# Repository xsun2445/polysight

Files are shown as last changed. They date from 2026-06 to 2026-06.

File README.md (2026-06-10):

<h1 align="center">POLySight</h1>

<h3 align="center">Towards Practical Bi-Static Polarimetric Imaging Using Commodity mmWave Radars for Material Sensing</h3>

<p align="center"><i>ACM/IEEE SenSys 2026</i></p>

<p align="center">
  <a href="https://xsun2445.github.io/polysight/">Project Page</a> |
  <a href="https://huggingface.co/datasets/xinghs/polysight">Dataset (Hugging Face)</a>
</p>

<p align="center">
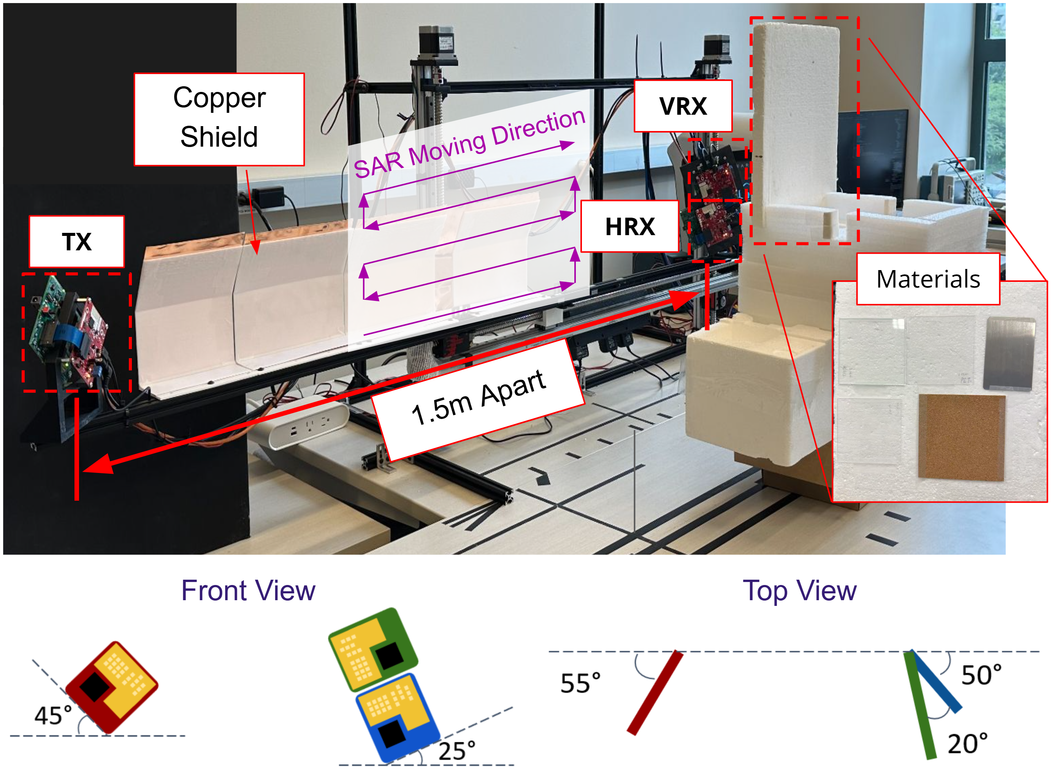
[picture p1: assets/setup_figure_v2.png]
Measurement setup
  
</p>

Polarimetric bistatic SAR imaging system for contactless material characterization at 77 GHz.

A single TX board (TI AWR2243) illuminates the scene while two spatially separated RX boards capture orthogonal polarizations (H, V). A 2-D motorized raster stage synthesizes a large aperture. The polarimetric ratio H/V, combined with Fresnel reflection inversion, yields complex permittivity (ε′ − jε″) of materials without physical contact.

<p align="center">
  Qualitative results
</p>

## Setup

```bash
uv venv
uv pip install -r requirements.txt
```

GPU acceleration (SAR generation) requires CUDA 12.x and CuPy.

## Pipeline

```
Collection → Decode/Sync → SAR Generation → Labeling → Permittivity Extraction
(collect.py)   (decode.py)   (sar.py + GPU)   (notebook)   (Fresnel inversion)
```

Detailed tutorials/implementations are inside the notebooks folder:
1. [Synchronization](notebooks/01_synchronization.ipynb)
2. [SAR generation](notebooks/02_sar_generation.ipynb)
3. [Liquid materials](notebooks/03_eval_liquids.ipynb)
4. [Solid and powder materials](notebooks/04_eval_solids.ipynb)
5. [Case study on sugar water concentration](notebooks/05_concentration.ipynb)

## Method

1. **Bistatic geometry**: TX and RX separated ~1.5 m, incidence angle 55°–60°
2. **Polarimetric ratio**: `div = SAR_H / SAR_V` (complex-valued)
3. **Amplitude → Fresnel ratio**: Normalize against metal reference, correct for antenna axial ratio, compute `p = tan(θ_pol)`
4. **Phase → loss tangent**: Extract referenced phase from H/V ratio
5. **Complex Fresnel ratio**: `p_complex = |p| · exp(−jφ)`
6. **Inversion**: `ε = (1 + 4p/(1−p)² · sin²θ_i) · tan²θ_i`
7. **Result**: `ε′ = Re(ε)`, `ε″ = |Im(ε)|`

## Dataset

The dataset contains 70 synchronized radar collections across 36 materials including plastics, ceramics, glass, wood, rubber, metals, liquids, and powders, measured at 55° and 60° incidence angles.

| Folder | Size | Contents |
|---|---|---|
| `raw/` | ~72 GB  | 70 synchronized radar cubes (~1 GB each)  |
| `labels/` | ~66 MB  | 84 SAR image collections with labels |
| `materials/` | ~1 MB | 72 cropped material sample files (.pkl) |
| `unsynced/`  | ~35 GB  | 2 example raw unsynchronized ADC captures |

See [data/README.md](data/README.md) for more details and selective downloading.

## Hardware

See [hardware/README.md](hardware/README.md) for more details

- **Radar**: 3 sets of TI AWR2243 FMCW (76–81 GHz) + DCA1000 EVM (ADC capture). Currently requires 3 PCs to config and re-trigger each of the radar with TI mmWaveStudio. todo: command line tool to replace the mmWaveStudio. A similar setup can be found in our MulDar repo: https://github.com/xsun2445/MulDar
- **Synchronization**: Raspberry Pi 4B
- **Motion stage**: 2-axis linear stage, 3 stepper motors + drivers, Arduino-controlled stepper motors

For more details please check out our paper: https://xsun2445.github.io/assets/pdf/Sensys_2026_PolySight.pdf

## Citation

```bibtex
@inproceedings{sun2026towards,
  title={Towards Practical Bi-Static Polarimetric Imaging Using Commodity mmWave Radars for Material Sensing},
  author={Sun, Xinghua and Gadre, Akshay},
  booktitle={Proceedings of the 2026 ACM/IEEE International Conference on Embedded Artificial Intelligence and Sensing Systems},
  pages={172--185},
  year={2026}
}
```

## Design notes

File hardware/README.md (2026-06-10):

# Hardware

<p align="center">
  Measurement setup
</p>

## Setup Overview

The PolySight hardware consists of three subsystems:

- **Radar**: 3 TI AWR2243 FMCW radar boards (76–81 GHz), each paired with a DCA1000 EVM for raw ADC capture. One board transmits (TX), two boards receive orthogonal polarizations (HRX, VRX). The TX and RX are separated by ~1.5 m in a bistatic configuration, with a copper shield isolating the TX antenna. Currently each radar requires a separate PC running TI mmWaveStudio for configuration and triggering.
- **Motion stage**: A 2-axis linear stage rasters the target across the radar aperture to synthesize a large SAR image. The vertical axis uses two stepper motors (left and right) for stability, and the horizontal axis uses one stepper motor. An Arduino controls all three motors via stepper drivers and sends a trigger pulse at each raster position.
- **Synchronization**: A Raspberry Pi 4B receives the trigger pulse from the Arduino (which corresponds to the SAR antenna locations on motion stage) and simultaneously triggers all three radar boards via hardware GPIO pins, ensuring time-aligned ADC captures across boards. Uses [WiringPi-Python-MultiPin](https://github.com/xsun2445/WiringPi-Python-MultiPin) for simultaneous multi-pin GPIO toggling.

## Directory Structure

```
hardware/
├── arduino/
│   └── motor_serialport_control.ino   # Arduino motor + trigger control
├── 3d_models/
│   ├── radar_frame_horizontal.stl     # Radar mounting frame (horizontal)
│   ├── radar_frame_22.5.stl           # Radar mounting frame (22.5° tilt)
│   ├── corner_reflector_30_1.5.stl    # Corner reflector (30 mm, 1.5 mm)
│   └── corner_reflector_50,1.5.stl    # Corner reflector (50 mm, 1.5 mm)
└── README.md
```

## Arduino Motor Control

The Arduino firmware (`motor_serialport_control.ino`) orchestrates the 2-D raster scan:

- **Vertical axis**: 2 stepper motors driven by the same step/direction signals for synchronized movement
- **Horizontal axis**: 1 stepper motor for lateral scanning
- **Trigger output**: GPIO pin 2 sends a pulse at each raster position to the Raspberry Pi
- **Serial interface**: Accepts commands from the host PC to configure scan parameters (speed, step count, grid size)

Pin assignments:

| Pin | Function |
|-----|---|
| 2 | Trigger (to Raspberry Pi) |
| 3, 8 | Vertical left motor (PUL, DIR) |
| 4, 9 | Vertical right motor (PUL, DIR) |
| 5, 10 | Horizontal motor (PUL, DIR) |

## Raspberry Pi Synchronization

The Raspberry Pi 4B acts as the hardware synchronization bridge between the motion stage and the radar boards:

1. Listens for the trigger pulse from the Arduino (one pulse per raster position)
2. Simultaneously toggles multiple GPIO pins to trigger all three AWR2243BOOST boards to start ADC capture
3. Uses [WiringPi-Python-MultiPin](https://github.com/xsun2445/WiringPi-Python-MultiPin) to set multiple GPIO pins in a single register write, minimizing timing offsets between radar boards

## 3D Models

STL files for 3D-printed mounting hardware:

- **Radar frames**: Custom brackets for mounting AWR2243+DCA1000 boards at horizontal or 22.5° tilt angles
- **Corner reflectors**: Calibration targets for SAR image verification

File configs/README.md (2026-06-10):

# Configs

JSON configuration files for Polysight data collection and processing. Each file
defines one aspect of the acquisition setup and is loaded at runtime.

| File | Purpose |
| --- | --- |
| `data_collection_cfg.json` | Scan geometry and per-acquisition radar parameters. |
| `devices_comm_cfg.json` | Chirp profile and communication/triggering setup for all devices. |
| `radar_id.json` | Static identity map of each physical radar board. |

## `data_collection_cfg.json`

Defines the raster scan grid and frame timing for a capture session.

- **Scan grid** — `dx`/`dy` step size, `total_x`/`total_y` extent, `moving_direction`
  (`"row"`/`"column"`), and `initial_position_pointer`.
- **Frame timing** — `num_trigger`, `period_frame`, `num_frame`, `num_chirp`,
  `num_config`, `vibration_pd`, `radar_timeout`.
- **Data shape** — `num_adc` (samples per chirp), `num_ch` (RX channels).
- **Geometry / mounting** — board distances and angles (`board_dist`,
  `txboard_angle_y`, `rxboard_*_angle_*`, `rxboard_tilt_offset`, `object_distance`).
- **Run metadata** — `retrigger_list`, `saving_root_dir`, `description`,
  `packet_zero_filling`.

## `devices_comm_cfg.json`

Defines the radar waveform and how the host talks to each device.

- **`chirp_configs`** — FMCW waveform: `f0`, `slope`, `ramp_time`, `adc_start_time`,
  `num_adc`, `Fs`, plus `activated_tx` / `activated_rx`.
- **`comm_cfg`** — device count and a block per node (`master`, `slave_*`, `motor`,
  `trigger`) giving `radar_name`, `port_type`, IP/serial port, and access port.

## `radar_id.json`

Per-board static identity, keyed by board index: `name` (e.g. `RH`, `RV`, `LS`),
`ip`, `mac`, and `cfg_port` / `data_port`. The `radar_name` referenced in
`devices_comm_cfg.json` maps back to the `name` here.

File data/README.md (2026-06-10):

# PolySight Dataset

Polarimetric bistatic SAR dataset collected with a 77 GHz FMCW radar (TI AWR2243).
Two radar boards receive orthogonal polarizations (RH, RV) while a single TX board
illuminates the scene. A 2-D motorized stage rasters the target across the aperture.

## Directory Structure

```
data/
├── unsynced/          # Raw unsynchronized ADC captures (2 example collections)
│   └── <collection>/
│       ├── RH/                   # Raw DCA1000 captures, H-pol RX (.bin + _log.csv)
│       ├── RV/                   # Raw DCA1000 captures, V-pol RX (.bin + _log.csv)
│       ├── LS/                   # Raw DCA1000 captures, TX (.bin + _log.csv)
│       ├── _adcData/RH/          # Decoded per-frame .npy files, H-pol
│       ├── _adcData/RV/          # Decoded per-frame .npy files, V-pol
│       ├── adcData/RH/           # Synchronized per-frame .npy files, H-pol
│       ├── adcData/RV/           # Synchronized per-frame .npy files, V-pol
│       ├── collection.log
│       ├── data_collection_cfg.json
│       ├── devices_comm_cfg.json
│       └── radar_id.json
│
├── raw/               # Synchronized radar cubes (70 collections, ~72 GB, ~1 GB each)
│   └── <collection>/
│       ├── RH_synced.npy         # Synchronized ADC cube, H-pol receiver
│       ├── RV_synced.npy         # Synchronized ADC cube, V-pol receiver
│       ├── data_collection_cfg.json
│       ├── devices_comm_cfg.json
│       └── radar_id.json
│
├── labels/            # SAR images + bounding-box labels (85 collections)
│   └── <collection>/
│       ├── sar_h.npy             # Complex SAR image, H-pol (150x150, complex64)
│       ├── sar_v.npy             # Complex SAR image, V-pol (150x150, complex64)
│       └── <collection>.json     # Label file (bounding boxes + SAR config)
│
├── materials/                    # Cropped material samples (see below)
│   ├── ceramic_60.pkl
│   ├── water_55.pkl
│   └── ...
│
└── README.md
```

## Download

The polysight dataset is hosted on Hugging face: https://huggingface.co/datasets/xinghs/polysight

Files are downloaded into the current directory, preserving the original folder structure.

| Folder | Size | Contents |
|---|---|---|
| `raw/` | ~72 GB  | 70 synchronized radar cubes (~1 GB each)  |
| `labels/` | ~66 MB  | 84 SAR image collections with labels |
| `materials/` | ~1 MB | 72 cropped material sample files (.pkl) |
| `unsynced/`  | ~35 GB  | 2 example raw unsynchronized ADC captures |

Use `download.py` to selectively download subfolders, install the Hugging Face Hub client:

```bash
pip install huggingface_hub
```

```bash
# List all available folders
python download.py --list

# Download a top-level folder
python download.py materials

# Download specific collections
python download.py labels/20250603_185728_oil_water labels/20250605_194155_water

# Download with glob patterns
python download.py "labels/20250625*"

# Download multiple folders at once
python download.py materials labels raw

# Download everything
python download.py --all
```

---

## Pipeline

```
unsynced/  ──[decode + sync]──>  raw/  ──[SAR generation]──>  labels/  ──[crop]──>  materials/
```

### 1. `unsynced/` - Raw ADC Captures

Raw ADC frames captured by three DCA1000 FPGA boards over Ethernet. Each radar
board produces independent packet streams that are **not yet time-aligned**.
These are provided as examples for reproducing the full decode and synchronization
pipeline (`polysight.collection.decode`). Most users can skip this stage and start
from `raw/`.

### 2. `raw/` - Synchronized Radar Cubes

Time-synchronized 3-D ADC data cubes, one per polarization channel:

- **`RH_synced.npy`** - Horizontal polarization receiver
- **`RV_synced.npy`** - Vertical polarization receiver

Each file is a NumPy array of shape `(num_positions, num_antennas, num_adc_samples)`
containing the decoded, packet-loss-corrected, and cross-board synchronized IF signal.
Generated from `unsynced/` data using `scripts/decode.py`.

### 3. `labels/` - SAR Images + Labels

SAR images generated from `raw/` cubes via GPU-accelerated FFT back-projection
(`scripts/generate_sar.py`, `notebooks/02_sar_generation.ipynb`).

Each collection folder contains:

- **`sar_h.npy`** / **`sar_v.npy`** - Complex-valued SAR images (150x150, complex64)
- **`<collection>.json`** - Metadata and bounding-box labels, created with
  `notebooks/03_labeling.ipynb`

The JSON label file contains:

```json
{
  "description": "1tx, oil, water, copper",
  "labels": {
    "oil":    [x0, y0, x1, y1],
    "water":  [x0, y0, x1, y1],
    "copper": [x0, y0, x1, y1]
  },
  "sar_config": {
    "numX": 350, "numY": 200,
    "dx": 0.002, "dy": 0.002,
    "output_size_x": 150, "output_size_y": 150,
    "chirp_configs": { "f0": 76.01e9, "slope": 38.8e12, ... },
    "antenna_configs": { ... },
    "ant_locs": [[x,y,z], ...],
    "RH_config": { "alignment_configs": { ... }, ... },
    "RV_config": { ... }
  }
}
```

### 4. `materials/` - Cropped Material Samples

Pickled dictionaries containing cropped SAR pixel regions for individual materials,
extracted from labeled SAR images. Each `.pkl` file represents one material measured
at a specific incident angle. Used by the evaluation notebooks for permittivity
estimation and material classification.

**File naming**: `<material>_<angle>.pkl` (e.g., `ceramic_60.pkl`, `water_55.pkl`)

**Structure of each `.pkl` file**:

```python
{
    "name":           str,        # Material name (e.g., "ceramic")
    "thickness":      float,      # Sample thickness in meters (e.g., 0.00127)
    "collection_name": str,       # Source collection (e.g., "20250623_182841_multi")
    "incident_angle": float,      # Measurement angle in degrees (e.g., 60.0)
    "ref_name":       str,        # Reference material name (e.g., "copper")
    "ref_thickness":  float,      # Reference thickness in meters
    "values":         list[ndarray],  # 3 complex64 arrays: [H/V ratio, H, V]
                                      # each shaped (rows, cols) from bounding box
    "ref_values":     list[ndarray],  # Same structure for the reference material
}
```

The `values` and `ref_values` lists each contain 3 arrays corresponding to the
H/V polarimetric ratio, H-pol, and V-pol SAR pixel regions cropped from the
bounding box. The polarimetric ratio (element 0) is used with Fresnel equations
to estimate relative permittivity via `polysight.eval.permittivity.ratio_to_epsilon`.

## Collection Categories

| Category | Count | Description |
|---|---:|---|
| liquids | 11 | Oil, water, soy sauce, syrup, sugar-water series  |
| solids | 24 | Plastics, wood, rubber, metals, composites |
| roughness | 3 | Wood grain orientations, sandpaper grits |
| ablation | 9 | Parameter sensitivity |
| concentration | 7 | Sugar-water concentration gradient (0-6 spoons) |
| ceramics | 8 | Alumina ceramic vs plastic at varying positions |
| misc | 8 | Oil, powder, rubber, PVC, mixed materials |

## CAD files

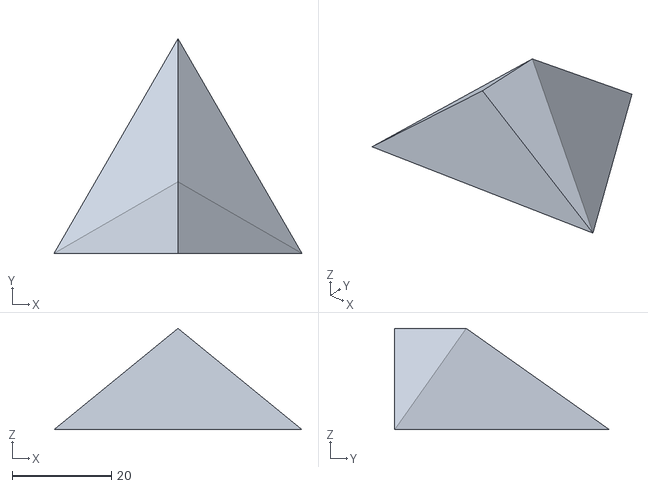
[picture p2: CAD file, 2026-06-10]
hardware/3d_models/corner_reflector_50,1.5.stl
50.0 x 43.3 x 20.4

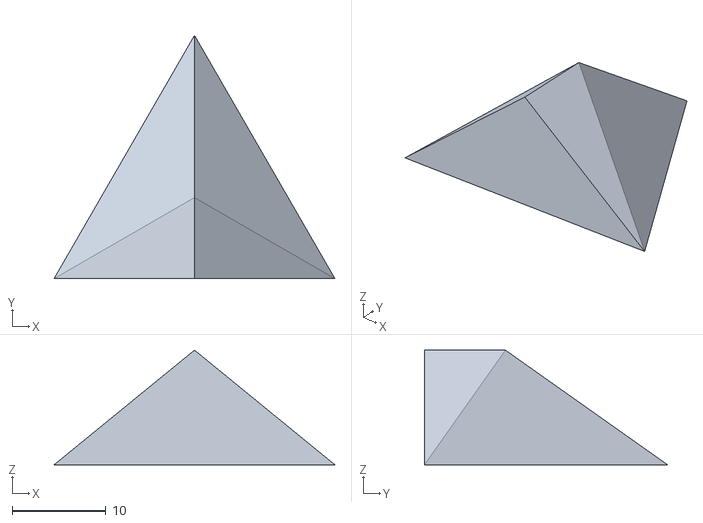
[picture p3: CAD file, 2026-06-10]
hardware/3d_models/corner_reflector_30_1.5.stl
30.0 x 26.0 x 12.2

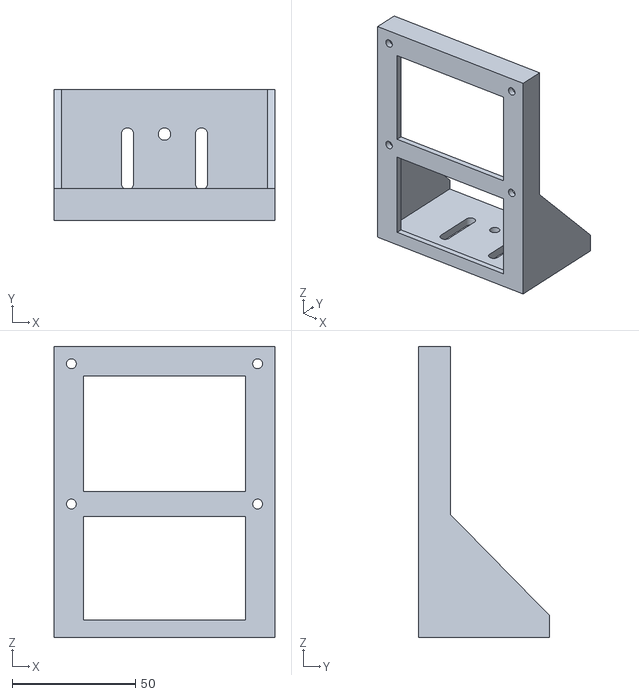
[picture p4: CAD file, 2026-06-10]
hardware/3d_models/radar_frame_horizontal.stl
89.6 x 53.0 x 118.0

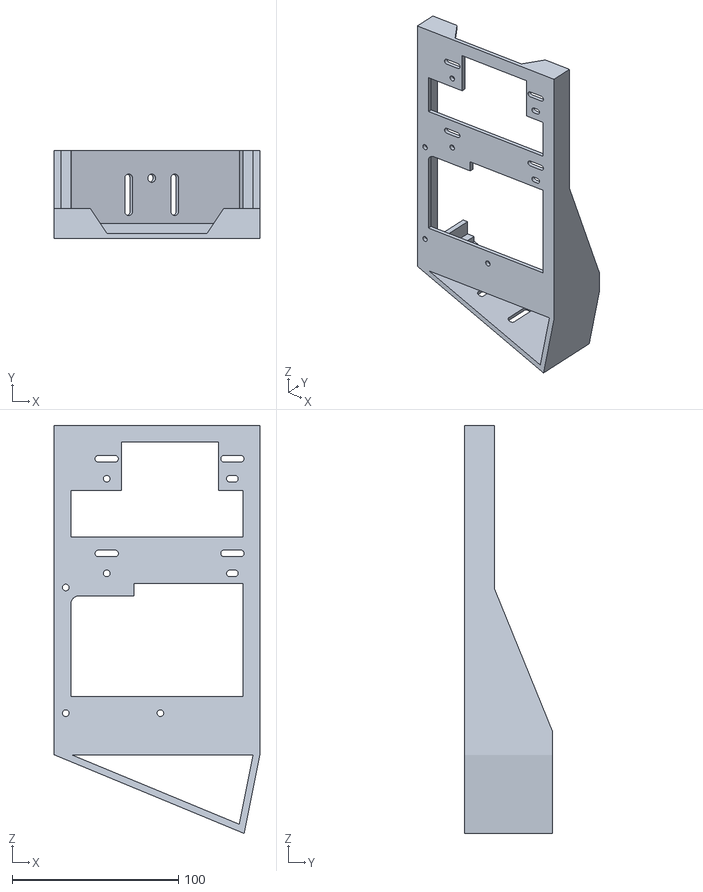
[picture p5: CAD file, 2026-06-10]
hardware/3d_models/radar_frame_22.5.stl
123.7 x 53.0 x 245.3

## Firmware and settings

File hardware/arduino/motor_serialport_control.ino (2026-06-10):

/*
  Combine H (2D) linear guide and another 1D linear guide for synchronous passthrough data collection. 

  Vertical rail: 2 stepper motors (left and right) for better stability, driven by same step signal and direction signal.
  Horizontal rail: 1 stepper motor.
  Trigger: 1 GPIO pin for triggering raspi which will trigger multiple radars through hardware trigger.
*/

#include <AccelStepper.h>
#include <math.h>

// for H rail
#define PUL_Ver_L 3
#define DIR_Ver_L 8
#define PUL_Ver_R 4
#define DIR_Ver_R 9
#define PUL_Hor 5
#define DIR_Hor 10
#define TRIGGER 2

// for 1D rail
#define PUL_1D 6
#define DIR_1D 11

// used as 5V pulled up
#define PULL_UP_0 12
#define PULL_UP_1 13


byte pul_ver_l = B00000001 << PUL_Ver_L;
byte pul_ver_r = B00000001 << PUL_Ver_R;
byte pul_hor = B00000001 << PUL_Hor;
byte trigger = B00000001 << TRIGGER;

byte pul_1d = B00000001 << PUL_1D;


long RATIO = 200;
// float speed = 23; // 50 -> about 40mm/s, // 23 -> 20mm/s
float speed = 6;
unsigned int pd = 1e6/speed/RATIO/2;


void setup() {
  Serial.begin(9600);
  Serial.setTimeout(10);

  DDRD = pul_ver_l|pul_ver_r|pul_hor|trigger|pul_1d;
  PORTD = B00000000;

  // pinMode(PUL_Ver_L, OUTPUT);
  pinMode(DIR_Ver_L, OUTPUT);
  // pinMode(PUL_Ver_R, OUTPUT);
  pinMode(DIR_Ver_R, OUTPUT);
  // pinMode(PUL_Hor, OUTPUT);
  pinMode(DIR_Hor, OUTPUT);
  // pinMode(TRIGGER, OUTPUT);
  pinMode(DIR_1D, OUTPUT);

  // pull up
  pinMode(PULL_UP_0, OUTPUT);
  pinMode(PULL_UP_1, OUTPUT);
  digitalWrite(PULL_UP_0, HIGH);
  digitalWrite(PULL_UP_1, HIGH);

}


void loop() {

  // Serial.println("Enter x,y:");
  while (Serial.available() == 0) {}     //wait for data available
  String teststr = Serial.readString();  //read until timeout
  teststr.trim();                        // remove any \r \n whitespace at the end of the String

  // input string will has length 4 each representing: H_x, H_y, 1D_x, step_to_trigger

  char *token = strtok(teststr.c_str(), ",");
  double cmdAry[4];
  int i=0;
  while( token != NULL ) {
      // cmdAry[i++] = atoi(token);
      cmdAry[i++] = atof(token);
      // cmdAry[i++] = strtol(token);
      token = strtok(NULL, ",");
  }
  
  double posx = cmdAry[0];
  double posy = cmdAry[1];
  double pos1d = cmdAry[2];
  double num_to_trigger;

  if (i > 3){
    num_to_trigger = cmdAry[3];
    pulse_train_trigger_byte(posx, posy, pos1d, int(round(num_to_trigger)));
  }else{
    pulse_train_byte(posx, posy, pos1d);
  }

  Serial.println("Done.");

}


void pulse_train_trigger_byte(double num_x, double num_y, double num_1d, int num_to_trigger) {

  num_x = long(round(num_x));
  num_y = long(round(num_y));
  num_1d = long(round(num_1d));
  // num_to_trigger = int(round(num_to_trigger));

  if (num_x > 0){
    digitalWrite(DIR_Hor, LOW);
  } else{
    digitalWrite(DIR_Hor, HIGH);
    num_x = -num_x;
  }
  if (num_y > 0){
    digitalWrite(DIR_Ver_L, LOW);
    digitalWrite(DIR_Ver_R, LOW);
  } else{
    digitalWrite(DIR_Ver_L, HIGH);
    digitalWrite(DIR_Ver_R, HIGH);
    num_y = -num_y;
  }

  if (num_1d > 0){
    digitalWrite(DIR_1D, LOW);
  } else{
    digitalWrite(DIR_1D, HIGH);
    num_1d = -num_1d;
  }

  long s = 0;

  // first will be in-place trigger
  PORTD = trigger; 
  delayMicroseconds(pd);
  PORTD = B00000000;
  delayMicroseconds(pd);

  while (s < num_x || s < num_y || s < num_1d){

    byte gpio_enable = B00000000;
    if (s<num_x) 
      gpio_enable |= pul_hor;
    if (s<num_y) 
      gpio_enable |= pul_ver_l | pul_ver_r;
    if (s%num_to_trigger == 0)
      gpio_enable |= trigger;
    
    if (s<num_1d) 
      gpio_enable |= pul_1d;

    PORTD = gpio_enable;

    delayMicroseconds(pd);
    
    PORTD = B00000000;

    delayMicroseconds(pd);

    s++;

  }
  // supplement triggering
  if (s%num_to_trigger == 0 && s!=0){
    // first will be in-place trigger
    PORTD = trigger; 
    delayMicroseconds(pd);
    PORTD = B00000000;
    delayMicroseconds(pd);
  }

}


void pulse_train_byte(double num_x, double num_y, double num_1d) {

  num_x = long(round(num_x));
  num_y = long(round(num_y));
  num_1d = long(round(num_1d));
  // num_to_trigger = int(round(num_to_trigger));

  if (num_x > 0){
    digitalWrite(DIR_Hor, LOW);
  } else{
    digitalWrite(DIR_Hor, HIGH);
    num_x = -num_x;
  }
  if (num_y > 0){
    digitalWrite(DIR_Ver_L, LOW);
    digitalWrite(DIR_Ver_R, LOW);
  } else{
    digitalWrite(DIR_Ver_L, HIGH);
    digitalWrite(DIR_Ver_R, HIGH);
    num_y = -num_y;
  }

  if (num_1d > 0){
    digitalWrite(DIR_1D, LOW);
  } else{
    digitalWrite(DIR_1D, HIGH);
    num_1d = -num_1d;
  }

  long s = 0;

  while (s < num_x || s < num_y || s < num_1d){

    byte gpio_enable = B00000000;
    if (s<num_x) 
      gpio_enable |= pul_hor;
    if (s<num_y) 
      gpio_enable |= pul_ver_l | pul_ver_r;
    // if (s%2 == 0) {pul_ver_l | pul_ver_r;} // for same speed as trigger function
  
    if (s<num_1d) 
      gpio_enable |= pul_1d;

    PORTD = gpio_enable;    

    delayMicroseconds(pd);
    
    PORTD = B00000000;

    delayMicroseconds(pd);

    s++;

  }
}


void pulse_train_trigger(double num_x, double num_y, int num_to_trigger) {

  num_x = long(round(num_x));
  num_y = long(round(num_y));
  // num_to_trigger = int(round(num_to_trigger));

  if (num_x > 0){
    digitalWrite(DIR_Hor, LOW);
  } else{
    digitalWrite(DIR_Hor, HIGH);
    num_x = -num_x;
  }
  if (num_y > 0){
    digitalWrite(DIR_Ver_L, LOW);
    digitalWrite(DIR_Ver_R, LOW);
  } else{
    digitalWrite(DIR_Ver_L, HIGH);
    digitalWrite(DIR_Ver_R, HIGH);
    num_y = -num_y;
  }

  long s = 0;

  while (s < num_x || s < num_y){

    // step motor
    if (s < num_x){
      digitalWrite(PUL_Hor, HIGH);
    }
    if (s < num_y){
      digitalWrite(PUL_Ver_L, HIGH);
      digitalWrite(PUL_Ver_R, HIGH);    
    }

    // trigger raspi
    if (s%num_to_trigger == 0) {
      digitalWrite(TRIGGER, HIGH); 
    }

    delayMicroseconds(pd);
    
    if (s < num_x){
      digitalWrite(PUL_Hor, LOW);
    }
    if (s < num_y){
      digitalWrite(PUL_Ver_L, LOW);
      digitalWrite(PUL_Ver_R, LOW);    
    }

    if (s%num_to_trigger == 0) {
      digitalWrite(TRIGGER, LOW); 
    }

    delayMicroseconds(pd);

    s++;

  }
}


void pulse_train(double num_x, double num_y) {

  num_x = long(round(num_x));
  num_y = long(round(num_y));

  if (num_x > 0){
    digitalWrite(DIR_Hor, LOW);
  } else{
    digitalWrite(DIR_Hor, HIGH);
    num_x = -num_x;
  }
  if (num_y > 0){
    digitalWrite(DIR_Ver_L, LOW);
    digitalWrite(DIR_Ver_R, LOW);
  } else{
    digitalWrite(DIR_Ver_L, HIGH);
    digitalWrite(DIR_Ver_R, HIGH);
    num_y = -num_y;
  }

  // Serial.println(num_x);
  // Serial.println(num_y);
  // Serial.println(STEPS);
  // Serial.println(s);
  long s_x = 0;
  long s_y = 0;

  while (s_x < num_x || s_y < num_y){
    if (s_x < num_x){
      digitalWrite(PUL_Hor, HIGH);
    }
    if (s_y < num_y){
      digitalWrite(PUL_Ver_L, HIGH);
      digitalWrite(PUL_Ver_R, HIGH);    
    }

    delayMicroseconds(pd);
    
    if (s_x < num_x){
      digitalWrite(PUL_Hor, LOW);
    }
    if (s_y < num_y){
      digitalWrite(PUL_Ver_L, LOW);
      digitalWrite(PUL_Ver_R, LOW);    
    }

    delayMicroseconds(pd);

    s_x++;
    s_y++;
  }
}


void printBin(byte aByte) {
  for (int8_t aBit = 7; aBit >= 0; aBit--)
    Serial.write(bitRead(aByte, aBit) ? '1' : '0');
}

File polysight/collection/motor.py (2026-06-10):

"""Stepper motor serial interface for 2D/3D motion stages."""

import serial


class Motor:
    """Motor controller using H-rail + trigger Arduino firmware."""

    def __init__(self, serial_port='COM3', baud_rate=9600, timeout=60, stepper_ratio=200):
        self.stepper_ratio = stepper_ratio
        self.serial_port = serial_port
        self.baud_rate = baud_rate
        self.timeout = timeout
        self.serial_device = serial.Serial(port=serial_port, baudrate=baud_rate, timeout=timeout)

    def __exit__(self):
        self.serial_device.close()

    def reconnect(self):
        self.serial_device.close()
        self.serial_device = serial.Serial(port=self.serial_port, baudrate=self.baud_rate,
                                           timeout=self.timeout)

    def move(self, *argv):
        """Move the stage by (dx, dy, [dtrigger]) in mm."""
        assert len(argv) == 2 or len(argv) == 3
        msg = ','.join([str(int(x * self.stepper_ratio)) for x in argv])
        self.serial_device.write(msg.encode())
        self.serial_device.readline()


class Motor_2d_using_3d(Motor):
    """2D motor adapter using 3 motors (one motor not used, d1d always 0)."""

    def move(self, *argv):
        """Move by (dx, dy, [dtrigger]) in mm, d1d fixed to 0."""
        assert len(argv) == 2 or len(argv) == 3
        d1d = 0
        cmd = list(argv)[:2] + [d1d] + list(argv)[2:]
        msg = ','.join([str(int(x * self.stepper_ratio)) for x in cmd])
        self.serial_device.write(msg.encode())
        self.serial_device.readline()
